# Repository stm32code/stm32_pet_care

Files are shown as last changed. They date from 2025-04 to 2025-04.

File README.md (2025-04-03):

基于STM32单片机物联网智能宠物看护版本1

本文旨在设计一种低成本、低功耗的系统，以STM32为核心芯片，用温湿度、压力、水位、光照等传感器来检测宠物所需的喂食、给水以及所处的环境条件，单片机经过与阈值的比较处理，驱动风扇模块，加湿模块，水泵模块，舵机模块，LED灯，使宠物达到理想生存环境。同时利用Wi-Fi技术将宠物喂养数据上传到OneNET物联网平台，由物联网平台将数据传送到手机APP进行数据监测与反向控制，适用于家庭、宠物店等环境。
绘制原理图和制作PCB板使用Altium Designer软件，相关程序使用Keil软件编程调试，使用OneNET物联网平台作为数据上传中心平台。经过调试最终实现设计目标

可实现如下功能：

1.实时检测宠物环境温度，湿度，光照强度；  																	OK

2.可以通过按键设置温度和湿度阈值，当温度高于（25）阈值时打开风扇降温，当湿度低于阈值60时，打开加湿器加湿；	OK

3.可以根据环境亮度自动调节灯光亮度，如果宠物需要休息也可以手动关闭灯光；									OK

4.可以监测宠物粮食余量，当宠物粮食不足时（<5）发出报警；  OK

5.可以监测宠物饮水机水量情况，当水量不足（<10）时自动加水；

6.可以使用手机APP远程控制系统的各种操作。

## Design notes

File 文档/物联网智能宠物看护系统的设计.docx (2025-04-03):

物联网智能宠物看护系统的设计

学生专业：
学生姓名：
指导教师：

# 摘 要

如今社会随着科学技术的进步和居民生活水平的提高，更多的人开始选择喂养宠物。然而，宠物喂养也存在不少难题。例如，由于工作、旅游和学习等原因，导致主人不能随时看护宠物，因此，为了解决宠物无人照料的问题，研制了一种能够自动给宠物喂食、喂水并为宠物提供合适的生活环境的宠物家庭系统。

本文旨在设计一种低成本、低功耗的系统，以STM32为核心芯片，用温湿度、压力、水位、光照等传感器来检测宠物所需的喂食、给水以及所处的环境条件，单片机经过与阈值的比较处理，驱动风扇模块，加湿模块，水泵模块，舵机模块，LED灯，使宠物达到理想生存环境。同时利用Wi-Fi技术将宠物喂养数据上传到OneNET物联网平台，由物联网平台将数据传送到手机APP进行数据监测与反向控制，适用于家庭、宠物店等环境。

绘制原理图和制作PCB板使用Altium Designer软件，相关程序使用Keil软件编程调试，使用OneNET物联网平台作为数据上传中心平台。经过调试最终实现设计目标

关键词：宠物看护；传感器；物联网平台；Altium Designer；Keil

# ABSTRACT

Nowadays, with the progress of science and technology and the improvement of residents' living standards, more people begin to choose to feed pets. However, there are also many problems with pet feeding. For example, due to work, travel and study, the owner cannot take care of the pet at any time. Therefore, in order to solve the problem of unattended pets, a pet home system that can automatically feed and water the pet and provide a suitable living environment for the pet is developed.

This paper aims to design a low cost, low power consumption system, with STM32 as the core chip, using pressure, water level, temperature and humidity, light and other sensors to detect the feeding and feeding water and environmental conditions required by pets, microcontroller after comparison with the threshold, driving fan module, humidifier module, water pump module, servo module, LED lamp, Make the pet achieve the ideal living environment. At the same time, the Wi-Fi technology is used to upload the pet feeding data to the OneNET Internet of things platform, and the Internet of things platform transmits the data to the mobile APP for data monitoring and reverse control, which is suitable for families, pet stores and other environments.

Altium Designer software was used to draw schematic diagrams and make PCB boards, Keil software was used to program and debug related programs, and OneNET Internet of things platform was used as the data upload center platform. After debugging, the design goal is finally achieved

Key words: Pet care，Sensor，Internet of things platform，Altium Designer，Keil

# 目 录

# CONTENTS

# 第1章 绪论

## 1.1 研究背景和意义

首先，随着人们生活，消费水平的提高，越来越多的家庭选择养宠物，这也为宠物市场的发展提供了机会。其次，由于很多场合，比如外出旅游、学习、工作等都无法将宠物带在身边，那么宠物的喂养在无人的情况下就难以得到满足。此外，随着人们对宠物健康和安全的关注度越来越高，他们也更关注宠物所面临的挑战和风险。因此，智能化的宠物管理监测系统可为消费者提供更加便捷和有效的服务。

其次是智能宠物看护设备的市场自我更新需要，随着物联网技术不断发展，相关产品的更新迭代越来越快，以及生活水平的提高，人们对于宠物的关注度也在不断上升，一般的产品不能满足用户的需求。同时也有越来越多的人开始投入到这一领域中来，越来越多的人开始尝试着去养宠物，从而带动了与宠物相关的市场迅速发展，并且还在以极高的速度快速发展与壮大。这就使得智能宠物看护产品在市场中也占据了一席之地。然而，智能宠物看护产品的快速发展也是一把双刃剑，由于市场中还没有足够多的智能化程度高且经济实惠的智能宠物看护设备，因此用户在使用过程中，所体验到的产品使用体验满意度较低，差强人意。

最后就是智能宠物看护设备便于宠物主人管理，物联网智能宠物看护系统可以为宠物主人提供一个便捷的宠物管理平台，可以让他们随时随地地对自己的宠物进行监测和管理，通过手机上的APP等终端设备，宠物主人可以实时了解到他们的宠物的健康状况、喂食等信息，及时采取措施对其进行照顾，同时也可以方便快捷地对其进行检查和诊断，及时发现问题并进行有效处理。能够有效解决目前因主人外出导致的宠物无人照看的问题

综上所述，物联网智能宠物看护系统的研究意义不仅仅在于可以为宠物提供更好的健康管理和喂养服务，还可以为宠物主人提供更为便捷的管理服务，实现更加智能化、自动化和个性化的管理。此外，随着物联网技术的发展，还可以实现智能家居建设，从而为宠物家庭带来更多便利和安全。

## 1.2 国内外智能宠物看护设备研究现状

### 1.2.1 国内研究现状

2017年，东南大学成贤学院电子与计算机学院的邵彦达、沈睿、眭耀宇发表的基于AT89C51单片机的智能宠物家居一文中，对于智能家居的研究中以AT89C51单片机为核心，利用几个I/O口实现对压力传感器的控制来实现对食物重量和饮用水重量的检测，来实现简单的宠物无人喂养，该设计简约方便，成本低，功耗低，且该设计抗干扰性能好，可靠性高[1]。但存在些许缺点，检测参数少，不能充分实现对宠物的喂养，另外不能实现远程监测和控制功能。2019年，周锦荣、张振宇、袁忠强设计的无线物联网控制的视频监控相结合的宠物喂养系统模型，以拓宽宠物智能喂养和管理方法为目的，使用STM32为主控芯片，驱动控制芯片，将以无线网络传感器为核心的物联网技术（IOT）应用到宠物喂食器的设计中，通过CCD传感器与微处理器控制技术，实现对宠物的智能喂食与监控，使宠物的饲养具有连接与感知的功能，从而提高饲养的精度与管理的效率[2]。但是没有遥控，只有喂食和监控的功能。2021年，由吴明泽，胡立夫，胡家瑞，吴晓宇等人联合研发，研制出了一款具有自主喂食、饮水、远程监控、远程控制等多种功能的智能宠物家庭。由STC89C51单片机作为平台，手机客户端和机器人终端构成，机器人终端使用摄影技术对宠物猫狗进行实时的录像，并通过视频通信技术将录好的视频发送到手机的客户端[3]。无线通信以网络为主要的传输媒体，机器人会按照主人制定的饮食规则，在一定的时间内给宠物们分发食物和饮料，并把宠物们的饮食信息发送到手机客户端。用户还可以通过电脑控制机器人上的摄像头，实时监控宠物的状态，保证宠物的喂食。缺点是成本较高，监测数据不全。

国内市场上有着不少宠物喂养设备，在京东APP上搜索查看后发现总体可分为两大类：单一喂食与喂水喂食两大类。其中单一喂食拿小米旗下的产品作为例子，众所周知如今的小米的智能家居生态链做的如火如荼，在宠物家居方面也是同样有所涉及。在京东上的一款产品可以连接米家APP，可随时随地控制出粮时间与数量，为宠物设置全天候定时定量自动喂食计划，放心出行，使喂养更科学更便捷[4]。但是缺点也显而易见：功能单一，仅有喂食功能，且不能监测宠物的生存环境状况。第二类就是既能喂食又能喂水，以联想旗下的产品为例：饮水、喂食、监控三合一减少多台设备的占地面积，让家里更整洁,宠物拥有更大玩耍空间一体化设计,防止宠物打翻。净水污水分离，可称重食盘，智能APP控制，红外高清摄像头，配备多猫识别功能。可谓是功能强大，一千多的价格也是令人望而却步，而且在用户的使用体验中也存在着不少抱怨，产品质量不合格，个别功能无法实现等。用户花了如此大的价钱却得不到相应的体验。总之如今的市场急需一款经济实用的智能宠物家居设备。

### 1.2.2 国外研究现状

现在，国外也在研究智能宠物家庭系统。2016年Kim Seungcheon在《Smart Pet Care System using Internet of Things》一文介绍了一种在物联网环境下工作的智能宠物护理系统。拟建智能宠物护理系统的基本服务包括:远程喂食、遥控自动排便、闭路电视服务、智能手机APP，可提供上述服务的控制信息[5]。自动给料机的基本功能和市场上能找到的产品大多是一样的。区别在于沟通能力和感知能力。设计了带有重量传感器和定时器的自动给料机。它可以测量食物的量和检查时间间隔。并可定时操作，设有定时装置。用户可以为宠物设定定时喂食时间间隔。此外，用户还可以根据一次性食物量的重量来设定食物量。每一个设置的控制都可以通过用户的智能手机完成。采用Arduino单片机实现了自动给料机。用户可以通过开发的特定智能手机APP查看自动给料机的状态。2020年Nenny Anggraini在研究《Mobile-based monitoring system for an automatic cat feeder using Raspberry Pi》中提出了一种基于树莓派的猫咪自动喂食系统，该项目的目标是利用一台网络摄像机，将一台步进马达与一台树莓派主机相连，用以监视猫咪吃食的情况。你可以用一个摄像头来拍照或者录像。步进马达可转动给料阀，经由GPIO管脚，向树莓派中插入程序。接下来，树莓派将连接到互联网和服务器网络，这样就可以通过移动端的网络浏览器或远程网络视图来完成系统控制。该系统的整体功能包括直接或定时给猫喂食，以及监测喂食周围的照片或视频[6]。

国外的实用设备也有不少公司在做，现列举以下几个公司，Petnet：这是一家位于美国的公司，主要生产智能宠物喂食器。它的智能喂食器可以通过智能手机应用程序进行控制和监测，可以根据宠物的体重、年龄、品种和活动水平等信息，自动计算每顿饭的分量和喂食时间；SureFlap：这是一家英国的公司，生产智能宠物喂食器和智能宠物门。它的智能喂食器可以通过微型芯片识别宠物，并根据宠物的食量和饮食需求，自动分配食物；Feed and Go：这是一家位于英国的公司，生产智能宠物喂食器。它的喂食器可以通过智能手机应用程序进行控制，可以设置多个喂食时间和分量，并监测宠物的食量和饮食情况。

整体上分析来说国外的智能宠物喂食产品存在的情况与国内大同小异，功能不够齐全，成本偏高，用户体验不够好。

## 1.3 设计主要内容

《物联网智能宠物看护系统的设计》以STM32单片机为主控，通过光照，温湿度,压力,水位传感器，来检测宠物需要的投食量供水量和适宜环境数据，单片机经过与阈值的比较处理，使驱动加湿模块，风扇模块，喂食喂水模块使宠物达到理想生存环境。同时利用Wi-Fi技术将宠物喂养数据上传到物联网平台，由物联网平台将数据传送到远端App进行数据监测与反向控制，适用于家庭、宠物店等环境。

主要研究内容分为以下三个部分:

1. 硬件系统部分：各传感器模块采集数据发送给主控芯片，根据主控芯片分析结果，控制水泵、风扇、舵机、加湿器等部分。
2. 物联网平台通信部分：与硬件接口部分、利用Wi-Fi模块与物联网平台通信部份、与软件系统接口部分。
3. 软件系统部分：通信的接口部分和客户端App界面部分。

# 第2章 总体设计方案

物联网智能宠物看护系统是对宠物平时的喂养看护进行的设计，本章会对不同的设计方案进行简单介绍与比较并选取最佳的方案来实现设计目标。

## 2.1 系统总体结构

系统总体结构框图如下图2-1所示

图2-1 系统总体结构框图

如图所示，整个设计以STM32F103C8T6为主控芯片，通过温湿度传感器，压力传感器，水位传感器,光照传感器来检测采集宠物的各种数据，然后传输到STM3单片机，经过处理后显示在OLED上，并且与预先设定好的阈值比较后，驱动加湿模块，风扇模块，投食供水模块，光照模块进行相应的动作。同时通过WiFi模块将采集到的各种数据上传到物联网平台，由物联网平台再将这些数据传送到手机APP终端来进行数据的监测与反向控制，完成整体系统的实现[7]。

## 2.2 设计方案的选择

整个系统设计不仅需要主控芯片完成对多个传感器：压力传感器，温湿度传感器，水位传感器，光照传感器采集的信息进行检测和读取并上传到物联网平台，还需要驱动风扇模块，加湿模块，投食喂水模块，光照模块。通过OLED屏幕和WiFi模块与手机连接后实现人机交互，对宠物生活的各项数据进行监测与管理。结合各方案的可行性研究，总结了以下几种主流的嵌入式智能宠物喂养系统的方案。

方案一：基于STC89C51的设计方案：STC89C51是STC MCU系列中的一种单片机芯片。该系统以FLASH核心为核心，运行速度快，运算能力强，外围设备丰富。下面是关于STC89C51的详情：

1. 内存：STC89C51包含32KB的闪存程式记忆体，可用来储存程式码及资料。另外，其SRAM容量为1KB。
2. 外设资源：STC89C51整合了多种外设资源，其中包含四个16位的计时器/计数器，两个串口（UART)，一个SPI总线接口，一个I2C总线接口，一个PCA计时/计数器，以及一个ADC模拟-数字转换器等[8]。
3. 接口：STC89C51的输入输出接口40个，其中常规接口32个，可编程中断接口8个。
4. 时钟部分：STC89C51以12兆赫兹的晶体振荡为主要频率，经锁相环倍频后，其工作频率最高可达72兆赫兹。
5. 电源部分：STC89C51芯片具有低功耗模式，掉电检测，重置电路等多种功率控制功能。
6. 编程方法：STC89C51支持内部系统编程（ISP）的编程方法，也就是说，可以在该系统中对FLASH程序内存进行直接的编程。

总结来说，STC89C51是一款有着非常优秀性能的单片机芯片，它拥有非常丰富的外部设置资源和强大的计算能力，并且还支持ISP编程，因此它可以被广泛地运用到各种应用中去。尽管STC89C51是一种性能优良的MCU芯片，但是STC89C51也有其不足之处，第一存储容量比较小：STC89C51的 flash程序存储容量仅为32KB，相对于现在的单片机芯片来说，稍显不足。第二缺少DMA功能：由于STC89C51没有直接存储器存储器存储器存储器直接存取（DMA）能力不足，造成了数据传输的效率比较低下。第三没有足够的中断向量：STC89C51仅仅支持5个中断向量，相对来说比其他芯片较少，可能会限制设计应用的需求。综上使用STC89C51作为主控芯片的话虽然在程序编程方面较简单，成本较低，但其处理能力有限，在运行多项功能时可能会发生宕机情况，造成芯片发热，数据异常等现象。

方案二：基于树莓派4B的设计方案：树莓派4B是由Raspberry Pi基金会开发的一款功能强大的单板计算机。首次发布于2019年，是树莓派3B+的升级版，提供了更高的性能和更好的扩展性，是一款功能丰富的单板计算机，可以广泛应用于物联网、机器人、智能家居等领域，以下是树莓派4B的主要特点：

1. 处理器：树莓派4B采用Quad-core Cortex-A72 64位ARMv8处理器，主频高达1.5GHz，比树莓派3B+性能提升三倍以上，可轻松运行各种应用程序和多媒体任务。
2. 内存：树莓派4B最高可搭载8GB LPDDR4-3200 SDRAM，比树莓派3B+提升四倍以上，能更快地处理大量数据，并运行更大规模的程序。
3. 存储空间：树莓派4B提供两个micro HDMI接口，支持4K显示输出，还有两个USB3.0接口，可使用更快的存储设备。
4. GPIO：树莓派4B提供了40个GPIO引脚，可用于连接各种传感器、执行器和其他外设。
5. 操作系统：树莓派4B可运行多种操作系统，包括Raspberry Pi、Ubuntu等，并支持Docker和Kubernetes等主流容器服务。

树莓派4B拥有着丰富的功能，但与此同时也存在一些缺点。首先，树莓派4B价格比之前的版本略高，这使得它在同类产品中并不是最为经济实惠的选择。其次，随着处理器性能的提升，整体功耗也有所增加，容易引起散热问题。使用时需要特别注意散热，否则会影响系统的稳定性和寿命。最后，由于硬件配置的变化，一些老的软件和扩展板可能不再兼容，需要重新编译或更新。

方案三：基于MSP430的设计方案：MSP430是由德州仪器（Texas Instruments）公司开发的具有极低功耗，高性能，操作简单的MSP430芯片。MSP430芯片因其独特的结构和优异的计算性能，在嵌入式、物联网等领域得到了广泛的应用。其主要特征如下：

1. 低功耗：MSP430的功耗非常低，它具有多种进入睡眠状态的方式，在低功耗模式下，耗电量可以降低到微安级别，非常适合于需要长时间待机的嵌入式应用。
2. 高性能：MSP430采用16位RISC架构，能够在相对较短的时间内完成复杂的运算，并支持DSP指令集和提供硬件加速器的FRAM存储器。
3. 易于编程：MSP430支持多种编程工具和编程语言，如MSP430-GCC、Code Composer Studio（CCS）和IAR Embedded Workbench等，还可通过USB接口进行在线编程和调试。
4. 强大的外设：MSP430内置了丰富的外设，包括多个定时器、比较器、ADC和DAC等，同时还支持多种通信接口和协议，如SPI、I2C、UART、USB等。

总之，MSP430芯片具有低功耗、高性能、易用等特点，在嵌入式、物联网等领域有着广阔的应用前景。但是也有其缺陷。首先，其处理器运行速度缓慢，仅为25MHz，不能满足高性能计算的需要。其次，一般情况下，MSP430的闪存空间仅为几KB至几十KB，不能满足较大规模的应用。此外，MSP430的外设资源相对较少，例如只有一个UART、一个SPI和一个I2C接口，无法满足复杂应用的需求。

方案四：基于STM32的设计方案：STM32单片机系列是一种以ARMCortex-M核为核心的嵌入式微处理器，这是一个面向高性能，低成本，低功耗，低功耗的嵌入式系统，其特征如下：

1. 较为丰富的外围接口：多个通用的输入输出口（GPIO）、模数转换器（ADC）、数字模拟转换器（DAC）、通用同步/异步收发器（USART）、串行外设接口（SPI）等等，可以满足用户的各种需求[9]。
2. 处理性能强：采用了ARM Cortex-M系列架构，处理性能高，适用于高速数据处理和复杂的算法。
3. 低功耗设计：STM32单片机具有较强的低功率特性，可根据需要自动切换到休眠状态和备份状态，从而达到最小化功耗的目的。
4. 灵活的开发工具和环境：STM32单片机可以使用多种开发工具如Keil、IAR等进行开发，同时也支持多种编程语言，如Assembly、C++等等。
5. 安全性高：STM32单片机具有硬件加密，防篡改，以及内部不掉电操作的保护等先进安全设计。

综上所述，STM32 MCU有较强的处理能力，较低的功耗，丰富的外部接口，灵活的开发方式，以及较高的安全性，可用于多种应用场合。虽然略微存在一些不足，比如需要更多的专业知识，对编程语言能力要求高等，但经过学习都可以克服。

通过以上四种方案的分析与对比，由于设计需要检测宠物各项生活数据，驱动各模块准确运行，与手机APP相接并反向控制等要求，且应具备低成本、可以量产商用的特性，并可以根据方案其他需求扩展相关外设，故选用方案四的基于STM32单片机的设计方案。

# 第3章 硬件设计

本章主要是对硬件部分进行设计，其中包括充最小系统电路，电源电路，WiFi电路，传感器部分，显示部分，按键部分，驱动部分，报警电路的介绍；

## 3.1 STM32F103C8T6最小系统

STM32F103C8T6是一款由意法半导体公司推出的基于Cortex-M3内核的32位微控制器，硬件采用LQFP48封装，属于ST公司微控制器中的STM32系列，它的GPIO有8种模式，包括上拉、下拉输入模式，所以在连接按钮时可以不设计上下拉电阻[10]。

STM32F103C8T6单片机具体参数如下：

1. GPIO：总共有37个GPIO，分别为PA0-PA15、PB0-PB15、PC13-PC15、PD0-PD1。
2. ADC：有2个12bit ADC合计12路通道，外部通道：PA0到PA7+PB0到PB1，内部通道：温度传感器通道ADC_Channel_16和内部参考电压通道ADC_Channel_17[11]。
3. Timers：4个16bit定时器/计数器，分别为TIM1、TIM2、TIM3、TIM、TM1带死区插入，常用于产生PWM控制电机；2个看门狗定时器（独立看门狗IWDG、窗口看门狗WWDG）；1个24bit向下计数的滴答定时器[12]。
4. 通信串口：2*IIC，2*SPI，3*USART，1*CAN。
5. 系统时钟：可以使用内部8MHz时钟HSI，最高倍频达到64MHz；也可以使用外部8MHz时钟HSE，最高可倍频可达到72MHz[13]。

STM32F103C8T6的最小系统主要由时钟电路，复位电路两部分组成，如下图3-1所示。其时钟电路包含两个主要部分：外部振荡器和内部时钟源。外部振荡器是用来提供芯片整体的系统时钟，通常使用一个陶瓷振荡器或者晶体振荡器作为外部振荡器，其频率通常为8MHz。此外，还可以连接一个30pF的并联电容以稳定振荡器的工作。

复位电路是一项非常重要的设计，它用于确保芯片在开机或者其他异常情况下能够正确地启动并进入预设状态。包括一个复位电平检测电路和一个RC电路，用于检测系统电源是否正常以及芯片是否工作不正常。当系统电源异常或者芯片出现故障时，复位电路会强制将芯片复位，进入复位状态，执行复位向量指向的地址，重新启动系统。

图3-1 STM32F103C8T6最小系统

## 3.2 电源部分设计

### 3.2.1 电源输入电路设计

电源输入部分考虑使用5V电源输入，一方面满足低功耗安全节能的目的，另一方面满足一些模块需要5V电压供电的需求，而对于STM32单片机和其他后续需要3.3V电压供电的模块，再进行电压转换。这里电源接入使用的是DC-005插座，材料耐高温，价格低廉，性价比高。电源输入电路原理图如下图3-2所示。

图3-2 电源输入电路原理图

### 3.2.2 WiFi电源转换电路设计

由于使用的WiFi模块ESP8266-01S的输入电压要求是3V-3.6V与STM32F103C8T6要求的电压相同，不可以使用电源直接输入的电压，所以这里需要设计一个WiFi电源转换电路将5V电压转为3.3V。

电源转换电路使用稳压器AMS117-3.3，它的稳压调整管是由一个PNP驱动的NPN管组成的，漏失电压定义为：

(3-1)

Vdrop————芯片内部导通时产生的压降;

VBE————三极管的基极和发射极之间的电压;

VSAT————三极管饱和电压

其基本电压转换公式为：

(3-2)

Vin————输入电压；

Vout————输出电压；

Vadj————外部校准电压。

其中Vdrop和Vadj在AMS1117的数据手册中提供了标准值[14]。需要注意的是，这里的输入电压和输出电压都是直流电压。如果需要将交流电压转换为直流电压，则需要使用整流和滤波等电路进行预处理。

在电源输入电路中，电容并联可以起到减少电源噪声、过滤掉高频噪声等作用，从而提供更稳定、更纯净的电源给负载电路。当电源由于传输线路、开关电源等因素导致的干扰噪声时，加入电容可以削弱这些噪声，起到去除干扰的作用。另外，电容并联还可以对电源电流进行平滑，防止瞬间电流过大造成电源电压下降，从而保证负载电路的正常工作。

具体来说，电容的充放电过程是一个相位相反的过程。当电源电压下降时，电容器可以通过释放其储存的电能，为负载电路提供额外的电流，从而稳定输出电压；当电源电压上升时，电容会吸收过剩的电流，防止过压，保护负载电路。转换电路的原理图如下图3-3所示。

图3-3 WiFi电源转换电路

为了保证AMS1117工作的稳定性，使用可调电压版本时，需连接至少一个22μF的钽电容至输出端，而固定电压版本则可使用较小的电容，具体容量还需据实际应用而定[15]。一般而言，随着输出电流增加，线性调节器的稳定性会降低。

## 3.3 WiFi模块部分设计

WiFi模块部分计划采用ESP8266-01S作为首选，可以用于快速连接互联网的物联网设备和小型嵌入式系统。ESP8266由中国乐鑫公司推出，是一种低功耗、低成本、高性能的系统级芯片，可在-40℃~125℃工作。选择使用ESP-01S型模块，它可以采用串口的无线AP（COM_AP）模式、串口的无线STATION（COM_STA）模式、串口的无线AP+STA（COM_AP&STA）模式，并且还具有一键配网（smartConfig）功能[16]。

ESP8266-01S这是一个类似于ESP-01的无线网络模块，但是在原来的基础上得到了更新和改善。本模组自带Wi-Fi功能，可与Wi-Fi直接联接，是一款性价比很高的物联网装置。ESP-01S具有八个插脚，其中两个插脚（VCC,GND)，两个TX/RX通讯插脚，四个GPIO插脚。电路原理图如下图3-4所示。各引脚功能介绍如下：

1. VCC：支持3.0V至3.6V电压输入的电源供电引脚。
2. GND：接地引脚。
3. CH_PD：芯片使能脚，用于将模块从低功耗模式的状态唤醒。
4. RST：重置引脚，将引脚电平拉低即可重置该模块。
5. TXD：串行通信发送数据，可以通过AT指令或固件程序来进行控制。
6. RXD：串行通信接收数据，可以通过AT指令或固件程序来进行控制。
7. GPIO0：通用的输入/出引脚，可控制LED和其他外部设备。
8. GPIO2：通用的输入/出引脚，可控制LED和其他外部设备。

图3-4 ESP8266-01S电路原理图

需要注意的是，在ESP8266ESP-01S通电后，系统将自动切换到串行烧录模式。如果要使固件程序正常运行，则必须同时拉高GPIO0和RST管脚（也就是与VCC连接）。

ESP8266-01S具有COM-AP模式，COM-STATIOM模式，以及COM-STA+AP模式，每一种模式都有其独特的作用和适用场合。其中，串口型的Wireless AP（COM_AP）模式，以该模块为热区，利用其它设备对ESP8266-01S模块进行访问，并利用串口进行信息交换。串口无线STA（COM_STA）模式则是将模块作为客户端，用于将模块接入其他热点来构建WiFi网络。而串口无线AP+STA（COM_AP&STA）模式则是既可以将模块作为热点，供其他设备访问，又可以接入到其他WiFi网络，它是前两种模式的综合[17]。

在开始初始化的时候，单片机通过串口通信的方式，模块的最初配置和发送命令的操作是利用AT指令来完成的，其中的一些AT指令见表3-1。

表3-1 AT指令

AT指令 | 描述
AT | 测试AT启动
AT+RST | 重新启用模块
AT+GMR | 查看版本信息
AT+GSLP | 开启深度睡眠功能
ATE | 开启和关闭回显功能
AT+RESTORE | 恢复原出厂设置
AT+UART | 设置串口的配置
AT+CWMODE=1/2/3 | 选择不同的工作模式

## 3.4 传感器部分设计

### 3.4.1 温湿度检测部分

温湿度检测部分利用DHT11温湿度传感器对宠物生活环境进行温度和湿度的监测。常见的DHT11有以下4个引脚，电气原理图如下图3-5所示。

1. VCC：传感器的正极供电引脚，工作电压的范围是3V到5V。
2. GND：传感器的负极供电引脚，需要进行接地。
3. OUT：传感器输出的数据信号引脚，可以通过单片机进行采集并处理。
4. RES：传感器的复位引脚，将引脚电平拉低一段时间即可对进行复位。

图3-5 DHT11电气原理图

应当指出，DHT11的数据信号管脚仅能进行数字输出，而不能进行模拟输出。当读取传感器的数据时，特殊的通信协议是必需的。DHT11在单片机能够读取一个确认信号时，就发出一个80微秒的高电平信号，并以50微秒的时间间隔将数据上传至MCU。湿度计算公式为：

(3-3)

RH——湿度值；

rh高——湿度数据高8位；

rh低——湿度数据低8位；

温度计算的方法同湿度的计算方式相同。基于此，可以读取此时的温湿度信息。在此状态下，传感器开启一次温湿度采集，然后通过ESP8266上传到物联网云平台。当采集完后，DHT11自动切换到低功耗模式[18]。

### 3.4.2 压力检测部分

HX711是一款24位模数转换芯片，用于高精密载荷传感器，它的特点是高集成度，高响应速度，高抗干扰能力。HX711在读出感测器数据时，使用差分输入方式，能有效地排除外界的干扰，使感测器的工作更稳定、更准确。支持两种工作模式：编程模式和工作模式。编程模式是用于初始化和校准HX711的内部参数，工作模式是用于读取外部传感器的数据。在使用HX711时，首先需要与外部传感器相连接。通常情况下，HX711需从外界传感器接受正、反两种输入讯号，才能对输出讯号进行差分读取。之后，经由PD_SCK (引脚选择位）、DOUT(数据输出管脚）与单片机进行SPI通讯，以实现数据的读出。

计算传感器供电电压：HX711可以在产生VAVDD和AGND电压，即HX711模块上的E+和E-电压[19]。通过下式（3-2）计算：

(3-4)

VAVDD——内部稳压电路的输出电压；

VBG——芯片的输出参考电压

例如：VBG为2.5V，R1=10K，R2=5.2K，因此得出VAVDD=7.31V。

测重原理：满量程输出电压=激励电压*灵敏度 (https://so.csdn.net/so/search?q=%E7%81%B5%E6%95%8F%E5%BA%A6&spm=1001.2101.3001.7020)1.0mV/V。例如：供电电压3.3V乘以灵敏度1.0mV/V=满量程3.3mV，相当于有3.3Kg重力产生时候产生3.3mV的电压[20]。

HX711该芯片需经四根管脚与单片机相连。其中，两个引脚为通讯用，另两个引脚为接收换能器的模拟电信号。原理图如下图3-6所示。

1. VCC：为芯片提供3.3V或5VDC供电的数字电源管脚。
2. GND：地线管脚，要求与该系统的地线相连。
3. SCK：MCU用于控制晶片内变换时序的时钟线路。
4. DOUT：在操作方式中，从其输出芯片测得的ADC值（24位）的数据输出管脚。

图3-6 HX711原理图

### 3.4.3 水位检测部分

液位传感器可采用物理接触法、压力传感法、声纳法等多种方法对液位进行检测。在此设计中，使用了Water Sensor作为水位感应器，该感应器是一种用于探测水位或水滴的辨识感应器，使用方便，性能价格比高。

Water Sensor有两个电源引脚VCC和GND，以及一个输出引脚：将检测到的水分信号转化为数字或模拟电信号输出，可以通过该引脚读取传感器检测到的水分含量数据。计算公式如下：

(3-5)

h——表示液位高度；

C——表示传感器测得的电容值；

C0——表示传感器在空气中的电容值；

k——表示传感器的灵敏度常数。

Water Sensor的检测原理是通过一系列的暴漏的平行导线线迹对水滴或者水量的大小进行测量进而判断水位[21]。在水与传感器的电极相接触时，将产生一个回路，使电流通过该回路，再回到控制系统中。该模块主要利用的是三极管的电流放大原理，当液位高度使三极管的基极与电源正极导通时，在三极管的基极和发射极之间就会产生一定的电流，这时在三极管的集电极和发射极之间就会产生一个一定放大倍数的电流，通过发射极的电阻产生特征电压，被AD转换器采集[22]。完成水位到模拟信号的转换之后，可以直接将输出的模拟信号连接至单片机，实现对水位进行测量。该传感器模块的电气原理图如下图3-7所示。

图3-7 水位检测原理图

### 3.4.4 光照检测部分

光照传感器（Light Sensor）是一种对外界光线进行检测的光电传感器。他们能侦测到光的出现以及光的明度，然后把这些量度转换成电信号，以便电脑或其它装置来读取。此部分采用光敏电阻5528，这是是一种根据内光电效应，把光照射到敏感表面上，使电阻值变化的半导体元件。光照越强，阻值就越低，随着光照强度的提高，电阻值急剧下降，甚至可小到1Ω以下[23]。因此，这种光敏电阻应用于光电传感器时，可根据光亮的强弱来进行控制。

单片机的PA5引脚用于AD采集，又因为STM32单片机的电压限制不能高于3.6V，而5528的电压为5V，所以为了使用两个电阻起分压作用来保证电压不超过单片机的正常工作电压。电气原理图如下图3-8所示。

图3-8 光照检测部分原理图

光敏电阻的阻值用R5528表示，PA5的电压用VAD表示，R11阻值为1000Ω，R12阻值为1500Ω，则可得下式：

(3-6)

单片机的正常工作电压为3.3V，ADC最大值为4096，将光敏电阻实时对应的AD值用X表示则可得下式：

(3-7)

然后将式（3-4）与式（3-5）联立可得：

(3-8)

通过ADC可以计算出X，也就可以根据上式求出光敏电阻的值，根据不同的电阻便可得到不同的光照强度大小。

## 3.5 显示部分设计

OLED屏幕具有高对比度、自发光、薄厚度、无需背景光源、宽视角、快速响应的优点。分为七针的SPI/IIC兼容模块，以及四针的IIC模块，设计中使用的是的四针的IIC模块。以现在的科技水平，OLED的体积还无法扩大，但分辨率却是可以达到的，这种屏幕的特点如下：

1. 0.96寸的发光二极管，有黄色、蓝色、白色三种色彩。
2. 分辨率为128x64。
3. 多种接口方式；OLED裸屏一共有以下种接口，分别是：6800,8080两种并行接口方式，3线或4线串行SPI接口模式，IIC接口模式（只要两条线路就能对OLED进行控制)，这五种接口是通过屏上的BS0-BS2来配置的[24]。

原理图如下图3-9所示。0.96英寸4针OLED有四根管脚，分别是正极（VCC）、负极（GND）、时钟线（SCL）、数据线（SDA)，其中VCC和 GND管脚是用来连接电源的，通常是3.3伏或者5伏。其中，SCL、SDA管脚分别为两条IIC接口的信号线路，用以与单片机进行通讯，完成对OLED器件的控制及数据传送。

图3-9 OLED原理图

## 3.6 按键部分设计

按键部分采用独立按键，是一种常用的电子器件，在电子器件中用来进行输入控制。它一般由一个按钮和连接到该按钮的两个引脚组成，当使用者按下按钮时，电路会接通，执行相应的动作。

独立按键个数很少，可以按照要求灵活地编写代码。而在矩阵式键盘中，键的位置则由行、列编号来决定。独立按键的工作原理比较简单，当按键被按下时，会断开引脚间的电路连接，并让单片机探测到电路中的变化，进而在程序中进行相关的控制与操作。

在利用STM32单片机进行按键转态读取时，将与按键相连的STM32单片机接口分配为1，若按下按键，因为按键的另一端接地，则该管脚被拉低。下图3-10为其原理图。

图3-10 独立按键部分原理图

共使用4个独立按键，这里命名为SW2、SW3、SW4、SW5。设计的功能分别为：用SW2控制模式的切换，即对温度，湿度的阈值进行设置；SW3按下为加；SW4按下为减；SW5为手动控制灯光的开关。

## 3.7 驱动部分设计

### 3.7.1 光照模块设计

光照部分计划使用LED灯来模拟宠物的灯光照射，有两种模式，第一种是自动模式灯光常亮，但是会根据光照传感器检测到的光照强度变换灯光的亮度，光照强度大即环境比较亮的时候，LED灯亮度较弱，当光照强度小即环境比较暗的时候，LED灯会随之变亮；第二种是手动模式，可以通过开关SW5来控制LED灯的亮灭，比如宠物需要休息时，可手动关闭灯光。

使用一个NPN型三极管（FHT9014Y-ME），为使NPN型三极管工作，需在其发射结加正向电压，集电结加反向电压的条件下才能达到导通电压[25]。发射结正偏表现为P端电压高于N端电压（需有适当的电压差），而集电结反偏表现为集电结电压高于基极电压。

图3-11 光照电路原理图

上图3-11为光照电路的原理图。当外部光线强度较弱时，光敏电阻的阻值较大，其两端电压升高，导致三极管基极电压上升，未能达到发射结正偏的条件，此时三极管集电极无电流通过，因此二极管不会发光；相反，在较强的光照下，光敏电阻阻值较小，其两端电压降低，基极电压随之降低并满足发射结正偏条件，此时集电极电压基本等于电源电压，高于基极电压，同时满足了集电结反偏条件，因此形成放大电路，有电流通过，二极管发光。并且光敏电阻阻值的变化，引起电压的变化，即LED灯光的亮度也会随之改变。

### 3.7.2 风扇及加水加湿模块设计

对于此部分计划使用三个继电器，来对风扇模块、加湿模块、加水模块进行模拟，并且可以直接在继电器的另一端接上相应的设备如：风扇，加湿器，水泵，继电器相当于开关使另一端对应的风扇、加湿器，水泵开始工作。

通过单片机接继电器电路，可以实现弱电对强电的控制。这种控制方式常见于工业自动化领域，如机器人、汽车生产线等的控制。通过单片机管脚的高低电平输入，可以实现对大电流负载的控制。

原理图如下图3-12所示。具体来说，MCU的一个输出端口连接到继电器控制电路中的控制端口，当该端口输出高电平时，继电器线圈不被激活，继电器处于关闭状态；当该端口输出低电平时，继电器线圈被激活，继电器吸合，处于闭合状态。这种电路可用于控制灯光、电机、风扇等大电流负载的开关。同时，接入LED灯能够非常直观地展示继电器的闭合情况，方便用户观察判断。

图3-12 继电器电路原理图

继电器驱动有两个主要含义：首先是对继电器本身进行驱动，因为继电器是一个功率器件，需要使用单片机来控制它的开/关状态；其次是利用其去驱动其他大功率负载，比如直接驱动接触器或者中间继电器。因此，继电器驱动不仅是单片机与外部大功率负载的接口，也是实现弱电信号控制强电负载的重要途径[26]。

### 3.7.3 投食模块设计

投食模块的设计采用一个舵机模拟宠物粮仓的开启和关闭，即当称重模块采集到食物重量不足时，经过单片机处理后发出信号，控制舵机旋转一个角度，表示进行投食。经常使用的标准SG90舵机共有三根接线：电源导线 VCC，接地导线GND，控制信号导线。其原理图如下图3-13所示。

图3-13 舵机原理图

舵机使用PWM信号进行驱动，其周期一般为20毫秒（50Hz），脉宽的范围为0.5毫秒到2.5毫秒。在每个周期内，舵机接收到一段PWM信号，通过信号的脉宽来确定需要转动的角度。理论上，脉宽为0.5毫秒对应着0度角，脉宽为2.5毫秒对应着180度角，中间的脉宽则会对应着这两个极端之间的角度值。不同脉冲舵机对应旋转角度如下图3-14所示。

图3-14 不同脉冲舵机对应旋转角度

单片机可以接收来自信号线的PWM控制信号，接着通过内部逻辑电路处理并输出控制信号，来控制舵机电机的转动。同时，电机驱动着齿轮组，经过减速后传动至输出的舵盘。此外，舵盘的输出轴与位置反馈电位计相连。在舵盘进行旋转时，位置反馈电位计也随之旋转，并输出电压信号给控制电路板进行反馈。控制电路板根据位置反馈信号来确定电机的转动方向和速度，从而使目标停止[27]。

## 3.8 报警电路设计

报警电路的设计目的是当宠物余量不足时发声警示。其电路主要由一个蜂鸣器，一个NPN三极管，一个隔离二极管以及一个偏置电阻组成。首先选择一个合适的蜂鸣器，它应该能够产生足够大的音量和频率来引起人们的注意。然后将蜂鸣器的正极连接到一个隔离二极管，以防止反向电流损坏电路。连接一个NPN三极管，将其基极与信号源即单片机的PA8引脚连接，中间接入偏置电阻R16进行保护，收集极与地线连接，发射极与蜂鸣器的负极相连，用来作为开关元件，将输入信号转换为输出信号。在报警电路中，三极管开关可以控制输出负载的通断，从而实现报警功能。报警电路如下图3-15所示：

图3-15 报警电路原理图

三极管的基极保持一个稳定的高电平，当PA8处于高电平状态时三极管反向截止，蜂鸣器无电流通过，不工作。当PA8处于低电平时，三极管导通，蜂鸣器通过电流形成回路发出声响开始工作，直到PA8再次拉高时停止报警。

# 第4章 系统软件设计

本章是对软件部分进行设计，主要是主程序流程设计，以及WiFi，传感器，OLED显示，驱动，物联网平台子程序的设计。

## 4.1 主程序流程图

本程序的主程序流程图如下图4-1所示。

图4-1 主程序流程图

软件主要实现如下功能：

1. 实时检测宠物环境温度，湿度，光照强度。
2. 通过独立按键设置适宜的温度和湿度阈值，当温度高于阈值时打开风扇降温，当湿度低于阈值时，打开加湿器加湿。
3. 根据环境亮度自动调节灯光亮度，也可以手动关闭灯光。
4. 监测宠物粮食余量，当宠物粮食不足时发出报警。
5. 监测宠物饮水机水量情况，当水量不足时自动加水。
6. 使用手机APP查看数据。网页下发指令控制。

程序开始后主控以及OLED屏幕初始化，LED初始化，按键初始化，水位初始化，舵机初始化，DHT11初始化，BEEP初始化，WiFi初始化最后进行称重模块初始化，并且对涉及的变量进行定义。然后判断WiFi模块的工作模式，默认为自动模式即ESP8266接受信号“I”时，当接受到信号“J”时开启手动模式；在自动模式下，各传感器将开始工作，采集信息数据并显示在OLED屏幕上。同时，数据也会被上传到物联网云平台。接着再次判断工作模式，为手动模式时则根据接受到的信号进行相应的动作；，否则直接将数据与所设阈值进行比较，然后判断是否通过按键改变阈值，没有则单片机发出信号使驱动模块进行相应的动作有则再次比较。当工作模式为手动时，各驱动模块根据下发的信号进行相应的动作，信号指令如表4-1所示。然后各传感器工作，采集的数据显示在OLED屏幕上，接着判断工作模式以此循环。

表4-1 信号指令表

信号指令 | 相应动作
A | 风扇开启
B | 风扇关闭
C | 加湿器开启
D | 加湿器关闭
E | 水泵开启
F | 水泵关闭
H | 舵机右转动90°
G | 舵机左转动90°
I | 自动模式
J | 手动模式

## 4.2 WiFi模块子程序流程图

如图4-2所示，首先，进行WIFI模块初始化并设置为STA模式工作，在该模式下ESP8266通过接收路由器的信号而能够连接互联网，如果把它安装在硬件设备上，就可以实现硬件设备的远程控制，可以理解为此时ESP8266是主动去连接其他设备[28]。判断是否连接成功，成功则进入下一步；若未连接则循环执行此步骤。直到连接成功，云平台的连接流程同上，云平台连接成功后，检查是否有数据收发任务。如果有，则执行收发任务；如果没有，则进行热点与云平台连接状态检查的循环。

图4-2 WiFi子程序流程图

## 4.3 传感器部分子程序流程图

按照总体方案设计，传感器信息采集与传输分为多个步骤。如图4-3所示，首先进行温湿度传感器数据采集，然后进行液位传感器信息采集，接着是光照传感器信息采集，最后进行压力传感器数据采集。采集到的数据由信息采集芯片对其进行处理，再由串行接口传送给通信芯片。然后，ESP8266模块会把资料传给OneNET的物联网云端，也会传给移动端的应用程序，实现数据的远程监测与管理。

图4-3传感器子程序流程图

## 4.4 显示子程序流程图

显示部分采用了0.96英寸的OLED显示屏来显示本地数据，并使用IIC控制方法进行数据通讯。当系统通电后，STM32单片机首先需要将与OLED相连接的引脚设置为IIC功能。然后，STM32单片机需要初始化OLED的寄存器，包括地址、片选等寄存器的配置。在初始化完成后，单片机会清空屏幕并开始展示所需的字符，这些字符包括温度湿度名称、亮度、水位、余量，在展示所有固定信息后，STM32单片机会显示每个器件的状态信息，对应于相应的字符。此时，STM32单片机已经成功接收到了每个器件的状态信息。详细的控制流程可参考图4-4。

图4-4 OLED显示子程序流程图

## 4.5 驱动部分子程序流程图

驱动部分程序流程图如下图4-5所示，程序首先进行初始化，如果WiFi模块连接失败则继续初始化，反之连接成功则将各传感器采集到的数据打包发送在OLED屏幕上显示。接着判断工作模式若为手动则根据下发信号控制各驱动模块工作；自动模式下则与阈值进行比较进而通过单片机控制各驱动执行相应命令。

图4-5 驱动部分子程序流程图

## 4.6 物联网云平台设计

### 4.6.1 MQQT传输协议

MQTT是一种以TCP/IP为基础，由IBM于1999年推出的一种基于发布/订阅的轻量级通信协议，现已更新到v3.1.1版本。在MQTT协议的通讯过程中，主要有三个角色参与：发布者（Publish）、代理/服务器（Broker）以及订阅者（Subscribe）[29]。

信息的发布方和订阅方均为客户端，而信息代理则由服务器来提供。同时，信息的发布方也可能是用户本身。通过MQTT协议实现，消息发布者将消息发送到服务器，服务器将消息传给订阅者，从而实现了消息的传输[30]。如下图4-6所示

图4-6 MQQT协议示意图

使用MQTT方式进行数据传输时，当使用的设备接入WiFi网络后，STM32单片机作为客户端会主动连接MQTT服务器。下表4-2为MQQT控制报文类型。

客户端在向服务器发送“CONNECT”报文之前，客户端需要完成一个关键步骤即连接入口的验证过程。一旦服务器确认连接有效，则会返回一个“CONNACK”报文。客户端可以是发布者也可以是订阅者，在实现数据通信前都需要连接到服务器，并完成“CONNECT”和“CONNACK”两个报文的交换。当客户端与服务器成功建立连接后，客户端的联机状态仍然会被客户端与服务器用来确认。

客户端必须周期性地将“PINGREQ”心跳数据包发送到服务器，以指示客户端的联机状态。一旦接收到一个“PINGREQ”的心跳数据包，服务器就会回复一个“PINGRESP”。如果一个客户端没有按时发送一个“PINGREQ”心跳数据包，那么这个客户端就会被服务器所切断[31]。

表4-2 MQQT报文控制类型

名字 | 值 | 报文流动方向 | 描述
Reserved | 0 | 禁止 | 保留
CONNECT | 1 | 客户端到服务端 | 客户端请求连接服务端
CONNACK | 2 | 服务端到客户端 | 连接报文确认
PUBLISH | 3 | 两个方向都允许 | 发布消息
PUBACK | 4 | 两个方向都允许 | QoS1消息发布收到确认
PUBREC | 5 | 两个方向都允许 | 发布收到
PUBREL | 6 | 两个方向都允许 | 发布释放
PUBCOMP | 7 | 两个方向都允许 | QoS2消息发布完成
SUBSCRIBE | 8 | 客户端到服务端 | 客户端订阅请求
SBBACK | 9 | 服务端到客户端 | 订阅请求报文确认
UNSUBSCRIBE | 10 | 客户端到服务端 | 客户端取消订阅请求
UNSUBACK | 11 | 服务端到客户端 | 取消订阅报文确认
PINGEEQ | 12 | 客户端到服务端 | 心跳请求
PINGRESP | 13 | 服务端到客户端 | 心跳响应
DISCONNECT | 14 | 客户端到服务端 | 客户端断开连接
Reserved | 15 | 禁止 | 保留

### 4.6.2 物联网控制台应用程序创建

登录OneNET官网注册自己的账号，然后进入到平台的开发者中心选项。点击控制台的多协议接入即可[32]。具体的添加产品如下图4-7所示。在完成创建产品后，还需要在该产品下创建设备，以对接硬件数据消息。

每个设备都有一个唯一的标识符（ID），可以使用鉴权码来确保它们之间的相互独立性。在创建一个产品时，需要填写名称、鉴权信息等信息，其中鉴权信息是用于验证设备或应用程序访问物联网平台的凭证。通过鉴权信息，可以对设备或应用程序进行身份验证，从而能够一定程度上保证数据的安全性和可靠性。

在本次设计中，设备名称为petcare，鉴权信息为dht11。设备详情信息如下图4-8所示。

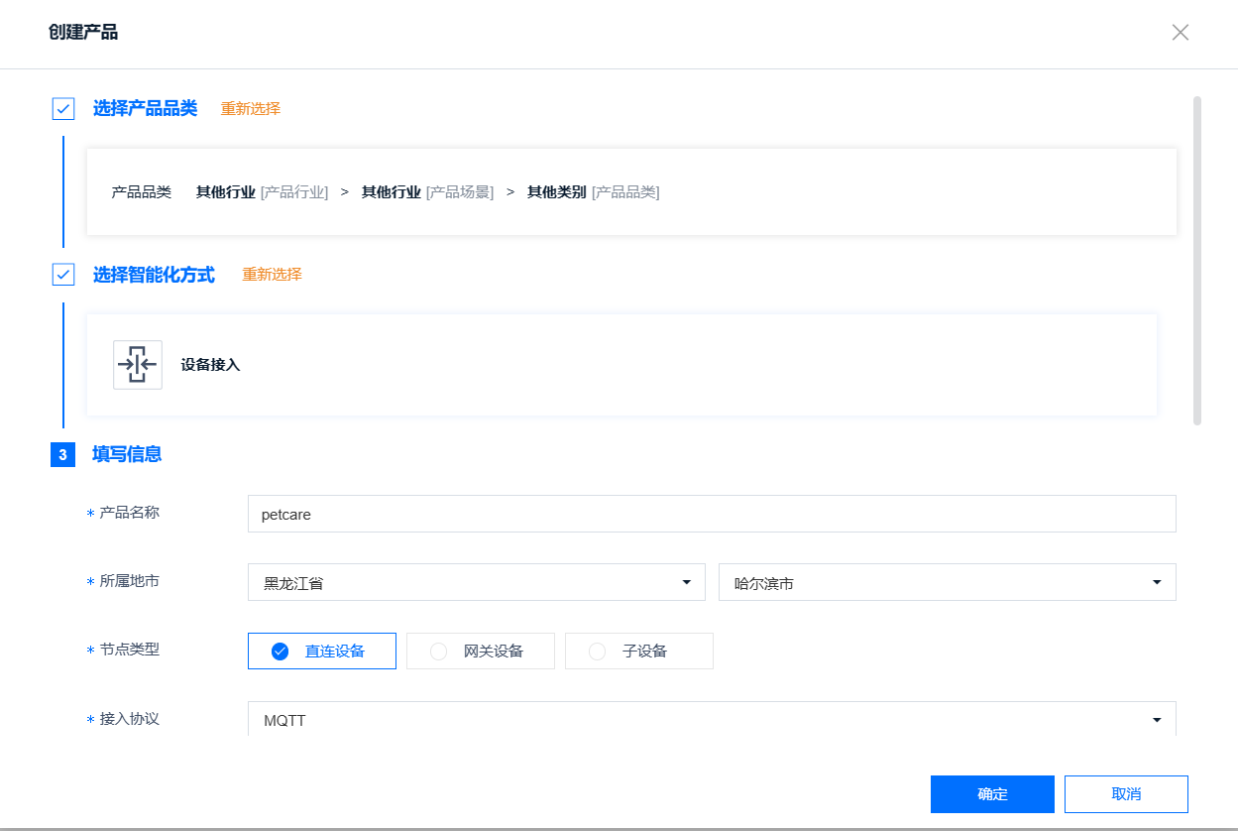
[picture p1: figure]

图4-7 创建的产品信息

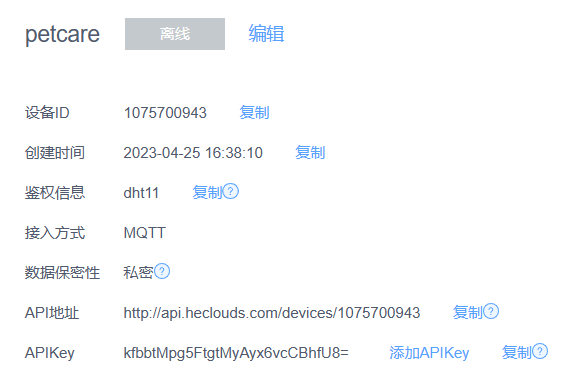
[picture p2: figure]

图4-8 加入设备信息

### 4.6.3 物联网平台通讯程序设计

如图4-9所示，物联网平台的通信流程如下：首先，任务初始化，然后检查ESP8266是否成功连接到OneNET物联网云平台；若连接成功，则执行下一步，否则循环检查直到成功为止。接着判断是否已登录云平台，如果失败则执行登录操作，并再次检查是否已登录。若成功登录，则检查是否收到了来自平台的数据。如果有数据，则解析并执行指令；如果没有数据，则检查是否需要将数据发送到云平台。如果需要，则执行“发送数据到云平台”指令；如果不需要，则返回到WiFi检查，并重复上述流程。

图4-9 物联网平台通讯子程序流程图

# 第5章 系统的调试与实验

本章为系统的实物制作与调试，主要是对PCB板的焊接与调试，以及软件部分的调试，硬件软件相互验证，以达到预期目标。

## 5.1 电路板的焊接与测试

电路板是控制器顺利运行的基础，也是所有元器件的支撑平台。电路板上的器件焊接质量是确保系统正常运行的前提。如果电路板上的器件焊接出现错误，那么下一步电源电路的测试就可能会对控制器造成不可逆转的损伤。因此，将电路板测试放置在整个测试流程的第一步非常重要[33]。

首先将制作好的PCB板与绘制好的原理图进行对比，使用万用表的测电阻功能对各个模块的引脚进行测试，确保连接无误。同时使用万用表仔细检查各焊点避免焊接过程中出现虚焊，缺焊的失误。另外还可以使用万用表在不供电的前提下检查各元件的正负极是否焊接正确。

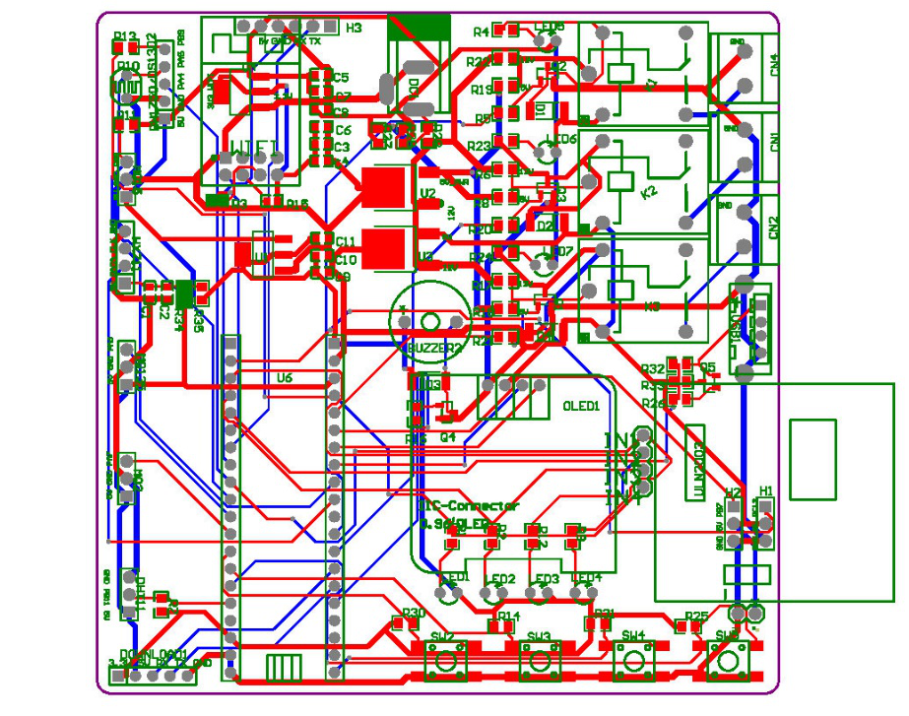
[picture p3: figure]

图5-1 PCB设计图

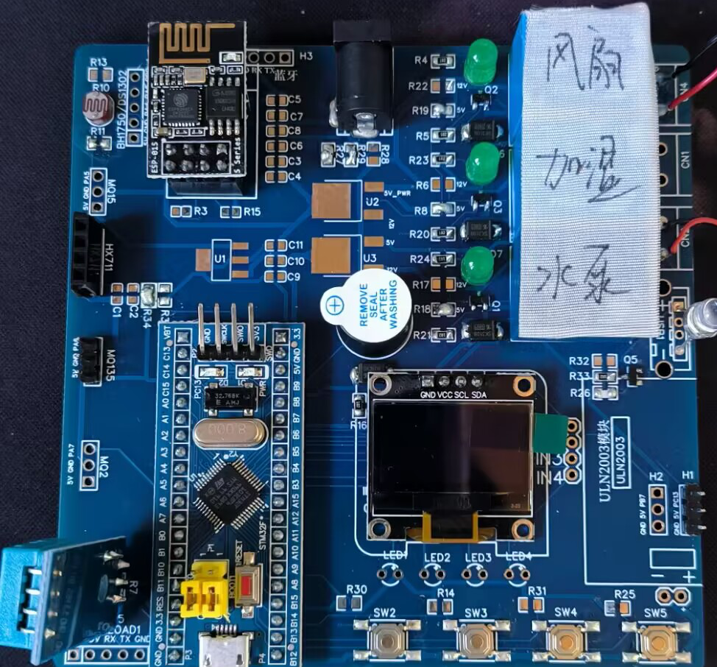
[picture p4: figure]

图5-2 PCB实物图

## 5.2 电路板上电调试

### 5.2.1 供电测试

硬件测试主要涵盖以下方面：OLED显示屏、WiFi模块、传感器数据采集模块、阈值设置和超出阈值后各驱动模块是否能按照设计要求驱动功能验证。

首先先进行电路板供电测试，为了避免线路短路损坏元器件，已经在上一步进行过线路检查。现在，将使用充电宝的5V供电口进行供电，并利用AMS1117稳压芯片将5V电压转换为3.3V电压[34]。同时，使用万用表对电路电压进行测量。当供电后电路板上各元器件工作正常。STM32单片机供电理论电压3.3V，实际测量电压3.29V，测量结果在误差范围之内，满足设计要求。测量结果如下图5-3所示。

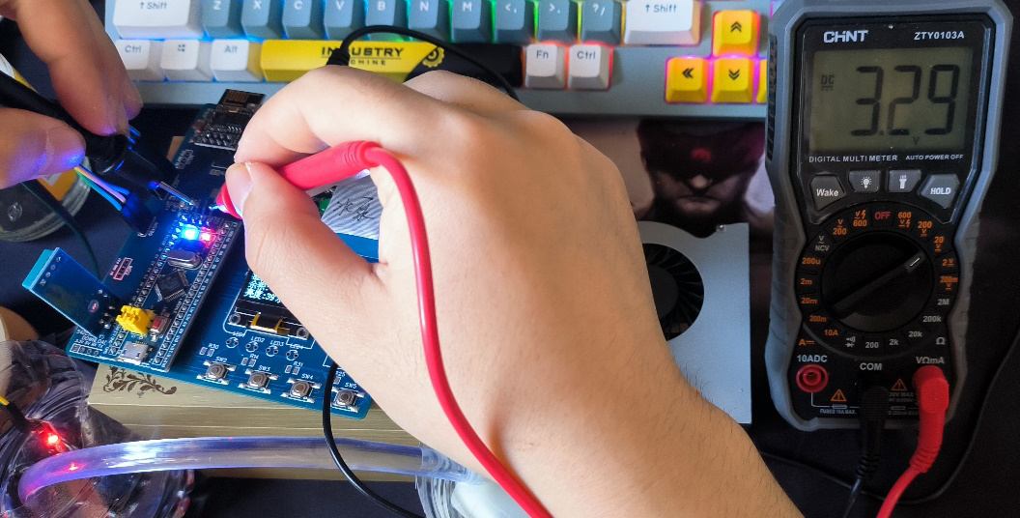
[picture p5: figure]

图5-3 供电测试

### 5.2.2 传感器数据采集功能测试

整个系统设计共包含以下几种传感器：温湿度传感器，水位传感器，压力传感器，光照传感器。在系统完成上电工作并运行一段时间后，各传感器将采集环境温度，湿度，水位，食物重量，光照强度等信息传送到物联网云平台，然后传输到手机端APP实时监测，同时也将在OLED屏幕上显示。测试结果如下图5-4所示。

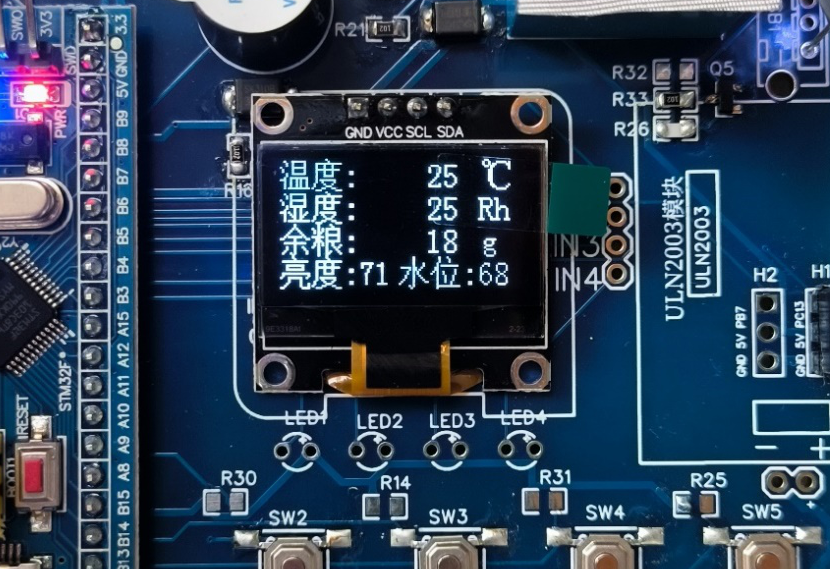
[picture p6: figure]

图5-4 传感器数据采集功能测试

### 5.2.3 驱动部分功能测试

驱动部分包括以下几个模块：风扇，加湿器，水泵，舵机，LED灯。当传感器数据采集功能正常运行后，进行下一步测试也就是驱动部分的功能验证，将电路板供电运行一段时间后，人为改变环境各数据，记录OLED屏幕显示的数据信息，并观察驱动部分相应动作，进行四组测试，系统阈值设定统一为：温度25℃，湿度60Rh，余粮5g，水位20。测试结果如表5-1所示。

表5-1 驱动部分测试结果

名称 | 第一组 | 第二组 | 第三组 | 第四组
温度 | 19℃ | 28℃ | 30℃ | 33℃
湿度 | 36Rh | 49Rh | 68Rh | 43Rh
水位 | 33 | 66 | 7 | 21
余粮 | 2g | 13g | 4g | 9g
光强 | 88 | 66 | 49 | 20
风扇 | 关闭 | 开启 | 开启 | 开启
加湿器 | 开启 | 开启 | 关闭 | 开启
水泵 | 关闭 | 关闭 | 开启 | 关闭
舵机 | 转动90° | 静止 | 转动90° | 静止
LED灯 | 较暗 | 暗 | 亮 | 较亮

根据以上四组测试结果可以得出驱动部分各模块工作正常，满足设计要求。另外可以通过四个按键SW2、SW3、SW4、SW5改变温湿度阈值以及控制LED灯的开关，在SW5按键按下后灯熄灭，再次按下灯亮，SW5按键工作正常。然后在表5-1中第二组的数据下通过按键改变温湿度阈值进行四组测试，测试结果如下表5-2所示。

表5-2 按键测试结果

名称 | 第一组 | 第二组 | 第三组 | 第四组
温度阈值 | 25℃ | 20℃ | 20℃ | 30℃
湿度阈值 | 60Rh | 45Rh | 65Rh | 55Rh
风扇 | 开启 | 开启 | 开启 | 关闭
加湿器 | 开启 | 关闭 | 开启 | 开启

## 5.3 软件部分调试

### 5.3.1 设备接入OneNET云平台测试

设备上电之后，可以正常工作，数据显示正常，现在进行WiFi连接，发现WiFi模块一直无法连接到手机热点，仔细检查代码后并无问题，在经过网上查找资料后找到了原因：ESP8266目前只能接受2.4Ghz的信号，而手机热点可以选择2.4G和5G，将手机热点频段改为2.4G后连接成功。如下图5-5所示。

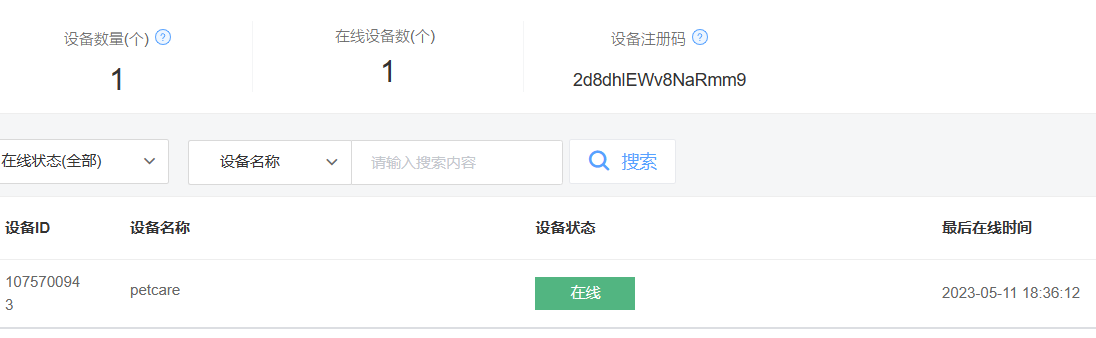
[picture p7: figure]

图5-5 设备在线记录

### 5.3.2 数据流监测

设备成功连接到OneNET云平台后，设备需要按照指定格式发送数据才能被平台接收。一旦平台成功接收到设备发送的数据包，用户可以在网页控制台或手机APP中查看数据流。这些数据流的名称是由单片机在上传数据时定义的。其中temperature和humility为温湿度传感器dht11测量的环境温湿度值，范围为0-100，单位分别为“℃”和“Rh”。shuiwei为水位传感器Water Sensor测量的数值，范围为0-100。yuliang为压力传感器HX711测量的数值，范围为0-50，单位为“g”。light为光照传感器测量的光照强度数值，范围为0-100。并且每个数据流可以根据不同时间段对测量数据进行详细的查看。比如点开light的数据流详情，可以看到每个时间段对应的光照强度大小。具体数据流数据查看如下图5-6所示

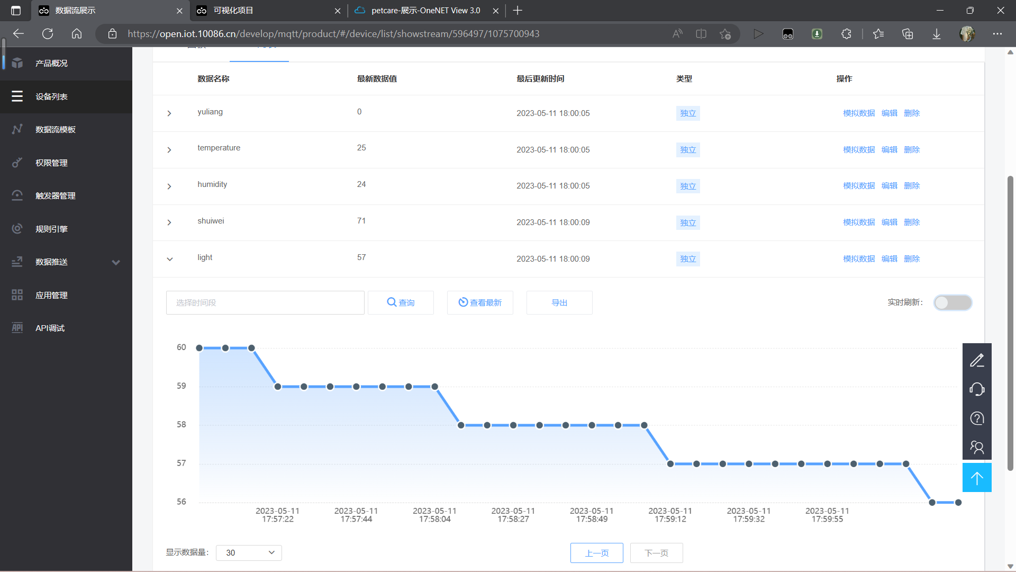
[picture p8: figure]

图5-6 网页端数据流显示图

手机端使用OneNET附带的APP设备云也可以进行监测，首先使用OneNET账号登录后，便可进行查看，如下图5-7所示。

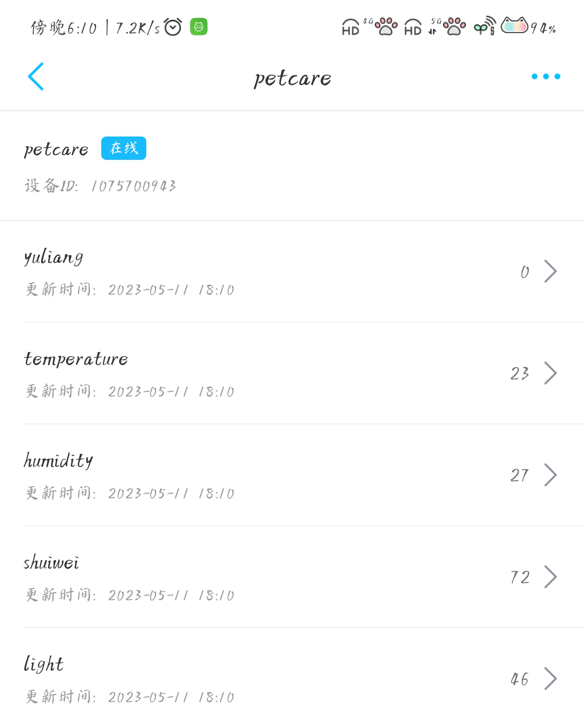
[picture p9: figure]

图5-7 手机端数据流显示图

在获取数据后，还可以通过OneNET物联网云平台的数据可视化服务将采集到的数据用图表的方式实时展现出来，便于更清楚更简单的查看相应的数据。可以自由编辑页面，可以选择网页类型：电脑页面或者移动端页面，这里选择创建一个电脑页面。然后选择使用仪表盘分别展示温度、湿度、水位、余粮和光照的实时大小，并用折线图显示这些数据的变化情况。制作完成效果如下图5-8所示。

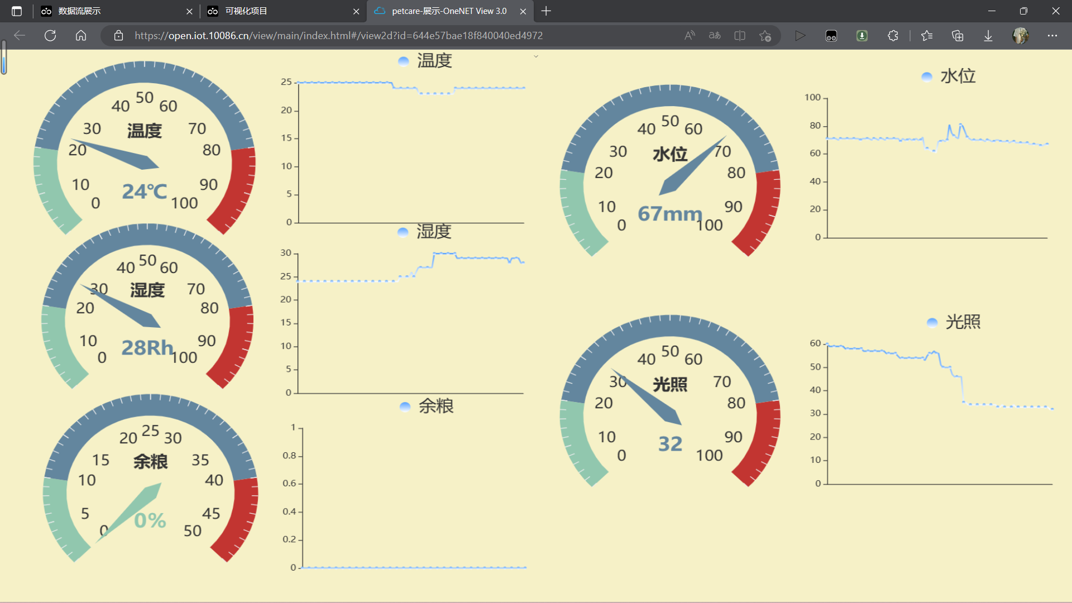
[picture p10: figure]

图5-8 数据可视化页面

在制作完成后还可以将制作的此项目发布，可以随时随地通过链接访问上述创建的数据可视化页面。

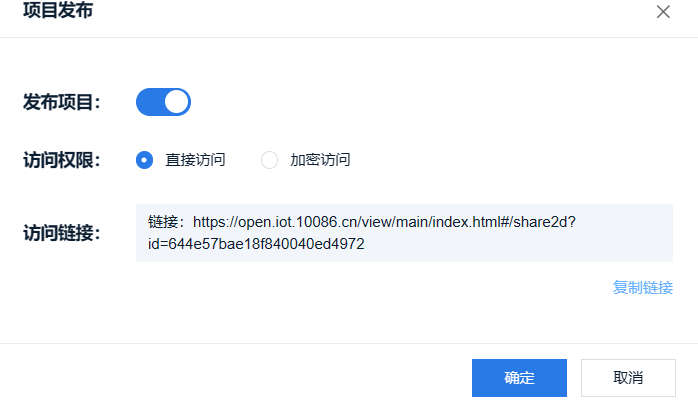
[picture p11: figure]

图5-9 项目发布

### 5.3.3 客户端远程控制测试

经过上面的各种调试，已经基本实现了设计要求，最后调试一下使用OneNET网页端远程下发指令控制设备实现相应动作，如下图5-10所示。下发命令对应的动作已经在上文的表4-1信号指令表中说明，这里不再赘述。

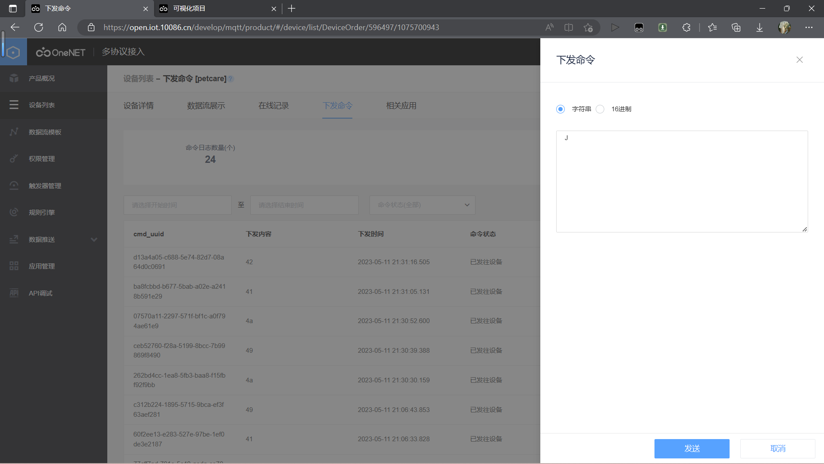
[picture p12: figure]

图5-10 下发命令页面

在调试过程中发现设备连接后下发命令，ESP8266指示灯闪烁表示WiFi模块已经接受到指令，但是设备并无响应，经过多次调试与检查后发现需要先下发命令“J”关闭自动模式后，再下发其他指令才可进行远程控制。下发指令“I”再次开启自动模式。将此问题弄清楚后，调试成功，进行了多次测试，设备均可准确运行。

到此整个设备调试完成，达到预期设计目标。

# 第6章 经济分析与环保分析

## 6.1 经济性分析

物联网智能宠物看护系统具有多项经济性优势。

首先，该系统可以通过智能化的监控和控制，降低照料宠物的成本。传统的宠物看护方式需要雇佣专业人员或者将宠物送到宠物店进行照料，这些方式都需要花费一定的费用。而智能宠物看护系统则可以通过智能喂食、自动换水等功能，降低了雇佣专业人员的成本，并且可以减少宠物寄养的费用。

其次，该系统可以提高宠物的健康水平，从而减少兽医费用。智能宠物看护系统可以通过实时监测宠物的饮食、生活环境各项数据，及时发现宠物的问题并采取相应的措施，从而减少宠物生病的概率。这样不仅可以降低兽医费用，还可以延长宠物的寿命，进一步降低了养宠物的成本。

第三，该系统可以提供更好的用户体验，增加用户黏性和忠诚度。智能宠物看护系统可以通过手机App等方式提供实时监控，让宠物主人能够随时随地监控宠物的情况，并及时做出相应的调整。这种个性化的服务可以提高用户的满意度，增加用户对产品的依赖和信任。

综上所述，物联网智能宠物看护系统具有多项经济性优势，可以降低成本，提高用户体验，是一项非常具有投资价值的技术。

## 6.2 环保性分析

能耗方面：使用的STM32芯片本身具有低功耗特点而且同时还保证了系统整体的正常运行，因此，整个系统有着很高的能耗比。

使用寿命：物联网智能宠物看护系统的寿命也是影响其环保性的因素之一。如果系统寿命较短，将会增加更新和更换的频率，导致更多的废弃物和资源浪费。因此，在设计系统时考虑到其长久的使用寿命，使用PCB打板代替普通洞洞板焊接，使得电路板的使用寿命大大延长。

健康安全：物联网智能宠物看护系统在使用中符合健康安全标准，不会对人和宠物造成伤害和危害。使用的是环保材料元件，以确保系统安全环保。

# 结 论

本文基于一款STM32单片机，使用多种传感器检测各项数据，在OLED屏幕上显示的同时将这些数据通过ESP8266模块上传到OneNET物联网云平台，可以在网页端实时监测也可以在手机APP上远程监测。系统设计有两种工作模式，自动模式下单片机会将数据与阈值比较，然后给驱动模块相应信号，使其做出相应动作。手动模式需要通过物联网平台先下发命令关闭自动模式，之后便可通过下发不同的命令信号控制驱动模块。

经过硬件电路设计和软件设计，成功完成了实物的制作以及调试工作。基本上能够实现远程看护宠物的要求，并且经济成本较低，微型化，低能耗能够广泛应用，传感器测量结果误差小，可靠性高，物联网技术迎合当前热门行业，具有广阔的发展空间。

由于时间原因和个人精力原因未能够做到完美，我认为还可以从以下几个方面进行改进和完善：

1. 不能监测宠物的运动轨迹，在后期研究可以加入定位功能或者加入摄像头实时监测宠物的状态。
2. 由于时间原因，硬件电路整体是无遮盖的，后续可以进行外观设计，3D打印一套外壳，使其更加美观实用。

# 参考文献

[1] 邵彦达，沈睿，眭耀宇.基于AT89C51单片机的智能宠物家居[J]. 科技创新导报，2017，14(14)：1-2.
[2] 周锦荣，张振宇，袁忠强.家居宠物智能喂食管理控制系统设计与应用[J]. 家畜生态学报，2019，40(04)：77-80.
[3] 吴明泽，胡立夫，胡家瑞，等.智能宠物护理机器人[J]. 中国科技信息，2021，(06)：79-80.
[4] 王凝.关于宠物喂食器的智能化发展趋势及设计方案研究[J]. 科技与创新，2022，(11)：93-95.
[5] Kim Seungcheon.Smart Pet Care System using Internet of Things[J]. International Journal of Smart Home，2016，10(3)：164-166.
[6] Anggraini Nenny，Rahman Dzul Fadli，Wardhani Luh Kesuma，et al.Mobile based monitoring system for an automatic cat feeder using Raspberry Pi[J]. TELKOMNIKA (Telecommunication Computing Electronics and Control)，2020，18(2)：354-357.
[7] 张帅，张迪，樊京，等.基于阿里云的电动汽车无线充电监控系统设计[J]. 电工技术，2021，(01)：102-104.
[8] 李雪健，陈燕春，夏文倩，等.黑板自动除尘系统[J]. 电子技术与软件工程，2022(20)：71-74.
[9] 张一波，董增寿，常春波.基于STM32F4的换热站控制系统的设计[J]. 太原科技大学学报，2021，42(06)：434-440.
[10] 迪力阿热木·吐尔地玉苏甫，郭斌.基于目标检测的自动断电实验台控制器的设计[J]. 电脑知识与技术，2022，18(18)：80-82+85.
[11] Biotechnology Companies; IAR Systems supports the new STM32 F0 low-cost ARM(R) CortexTM-M0 microcontrollers from STMicroelectronics(R)[J]. Technology & Business Journal，2012：67-70.
[12] Ganssle， Jack G.Watchdogs redux[J]. Embedded Systems Design，2011，24(2)：261-265.
[13] 魏永生.STM32单片机定时数据采集系统参数设置与编程[J]. 电子元器件与信息技术，2022，6(03)：23-25+28.
[14] 詹治国，林少波，郭栋，等.智慧楼宇通信技术架构及关键技术研究[J]. 计算机测量与控制，2022，30(12)：175-179+217.
[15] 孔祥斌. 某产品水下运动姿态测量系统设计[D]. 中北大学，2014：18-19.
[16] 张桂莲，石宜金，谭贵生，等.基于点灯科技的智能家居控制系统设计[J]. 现代信息科技，2023，7(08)：185-188.
[17] 沈晨航，周俊.基于ESP8266WiFi模块和MQTT协议的游泳馆水质监测系统设计[J]. 数字技术与应用，2020，38(05)：148-151.
[18] 史艳红，张玉杰.基于ZigBee和LabVIEW的多地无线温湿度监测系统设计[J]. 机床与液压，2015，43(22)：131-134.
[19] 王娇娇，田歌，王巧华，等.一体式禽蛋呼吸检测装置设计与试验[J]. 食品科技，2023，48(01)：50-55.
[20] 周乃迅，董文志，邓航宇.基于STC89C52的单手式水果称重采摘器研究[J]. 南方农机，2019，50(17)：27-28.
[21] Sawicka Marta J，Wróblewska Elwira K.The application of 7H-indolo[1，2-a]quinolinium merocyanine as a new water sensor in organic solvents.[J]. Chemicke zvesti，2018，72(3)：78-82.
[22] 骆雪汇，纪正辉，覃沛泳，等.微生态花园控制系统设计[J]. 机电信息，2023(06)：46-49.
[23] 朱磊，李辉，李广政，等.一种新型智能晾衣架系统设计[J]. 船电技术，2023，43(02)：38-41.
[24] 陈长征，窦宝茹，师亮.基于STM32单片机的智能停车场车位管理系统的设计与实现[J]. 西安航空学院学报，2020，38(05)：60-64.
[25] 蒋丹.识别“八大元件”的快捷技法[J]. 职业，2006(S1)：107-109.
[26] 宋锦.电子密码锁设计与调试[J]. 电脑知识与技术，2011，7(33)：8218-8220.
[27] 周树勋. 小型无人直升机机载飞行控制系统研究与设计[D]. 上海交通大学，2012：16-19.
[28] 张伟涛，刘保菊.智能化蔬菜大棚的设计与实现[J]. 工业控制计算机，2023，36(05)：154-155+158.
[29] 黎扬，何适.基于CANoe MQTT节点仿真的T-Box远程功能自动化测试[J]. 汽车电器，2022(07)：91-92+95.
[30] Ali Jawad，Haseeb Zafar Mohammad. Improved End-to-end service assurance and mathematical modeling of message queuing telemetry transport protocol based massively deployed fully functional devices in smart cities[J]. Alexandria Engineering Journal，2023，72：547-549.
[31] 王红玉. OneNET云平台下基于WiFi的智能家居监控系统的设计与实现[D]. 内蒙古大学，2021：42-44.
[32] 李嘉明，冯建，廖明华，等.基于ESP32的电子秤系统设计[J]. 电脑知识与技术，2021，17(12)：216-219.
[33] 陈陈. 基于阿里云IoT平台的智能空调控制系的设计与实现[D]. 合肥工业大学，2021：61-65.
[34] Diaconu E.M..Electrical Device Control System Through Wi-Fi Technology[J]. The Scientific Bulletin of Electrical Engineering Faculty，2021，21(1)：407-408.

# 附录1 系统硬件电路图

# 附录2 系统部分程序代码

int main(void)

{

u8 a=0;

u8 val = 0;

Timer_SRD_Init(9998,7199);//time3 定时器初始化

NVIC_PriorityGroupConfig(NVIC_PriorityGroup_2);

delay_init();

OLED_Init();

LED_Init();

KEY_Init();

Adc_Init();

SG90_Init();

DHT11_Init();

TIM2_PWM_Init(100,719);

uart_init(115200);

uart2_init(115200);

WiFi_RxCounter=0; memset(WiFi_RX_BUF,0,WiFi_RXBUFF_SIZE); WiFi_ResetIO_Init();

u1_printf("U1 OK");

u2_printf("U2 OK");

SG90_angle(90);

delay_ms(100);

LED_AllOff();

BEEP_OFF;

RELAY1_OFF;

RELAY2_OFF;

RELAY3_OFF;

SG90_angle(0);

OLED_Clear();

Init_HX711pin();

delay_ms(100);

Get_Maopi();

delay_ms(100);

Get_Maopi();

delay_ms(100);

OLED_ShowCH(0,0,"温度:");

OLED_ShowCH(102,0,"℃");

OLED_ShowCH(0,2,"湿度:");

OLED_ShowCH(101,2,"%");

OLED_ShowCH(0,4,"余粮:");

OLED_ShowCH(102,4,"%");

OLED_ShowCH(0,6,"亮度:");

OLED_ShowCH(60,6,"水位:");

while(1){

if(strstr(WiFi_RX_BUF,"I"))

{

u1_printf(WiFi_RX_BUF);

auto_k1=1;

WiFi_RxCounter=0;

memset(WiFi_RX_BUF,0,WiFi_RXBUFF_SIZE);

}

if(strstr(WiFi_RX_BUF,"J"))

{

u1_printf(WiFi_RX_BUF);

auto_k1=0;

RELAY1_OFF;

RELAY2_OFF;

RELAY3_OFF;

WiFi_RxCounter=0; memset(WiFi_RX_BUF,0,WiFi_RXBUFF_SIZE); }

if(auto_k1==0)

{wifi_C();

if(sg90munber==0) SG90_angle(0);

if(sg90munber==90) SG90_angle(90);

delay_ms(100);

}

if(KEY1_IN_STA==0){

delay_ms(100);

if(KEY1_IN_STA==0){

val++ ;

OLED_Clear();

}

}

if(KEY4_IN_STA==0){

delay_ms(100);

if(KEY4_IN_STA==0){

light_onoff ++;

}

}

switch (val%3)

{case 0: if(a%10==0)

{get_shuju();

a=0;

}

break;

case 1: set_wendu();

break;

case 2: set_shidu();

break;

default: return 0;

}

if(auto_k1==1) auto_kongzhi();

}

}

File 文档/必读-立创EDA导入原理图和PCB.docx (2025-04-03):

# 1. 软件下载网址：

软件下载 - 嘉立创EDA (lceda.cn) (https://lceda.cn/page/download)

按照电脑配置下载对应的版本。并安装。

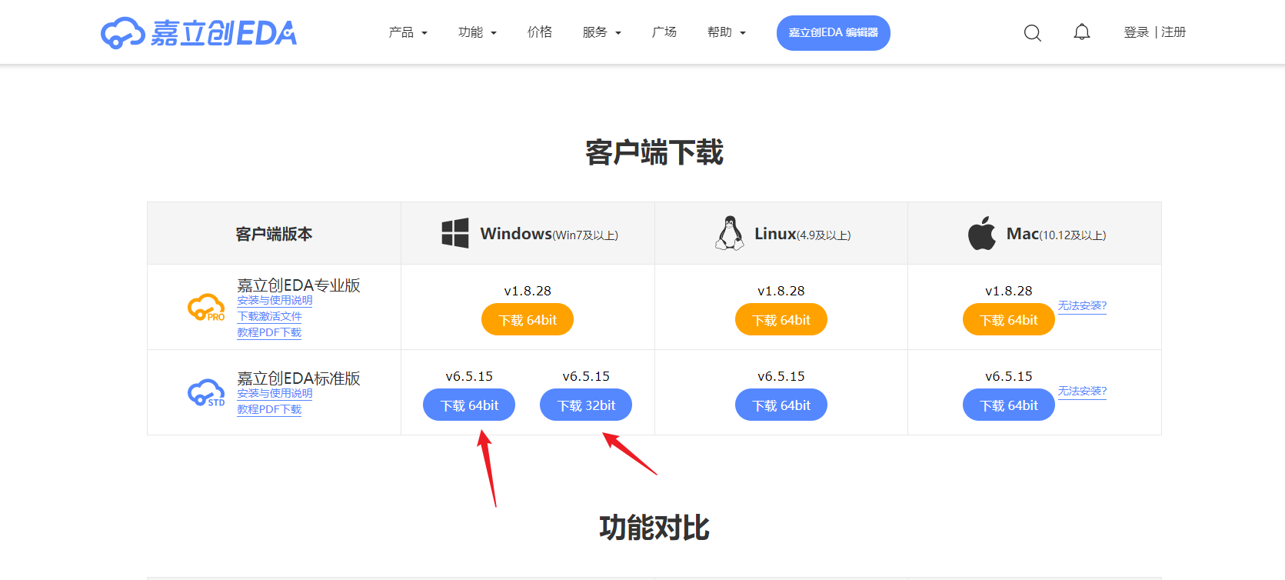
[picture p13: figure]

# 2. 导入原理图和PCB

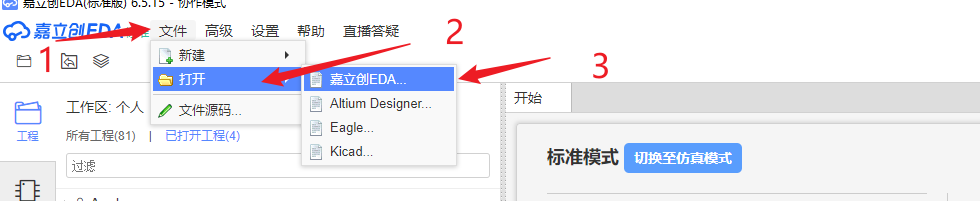
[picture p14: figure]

2.选择.json 文件打开

3.

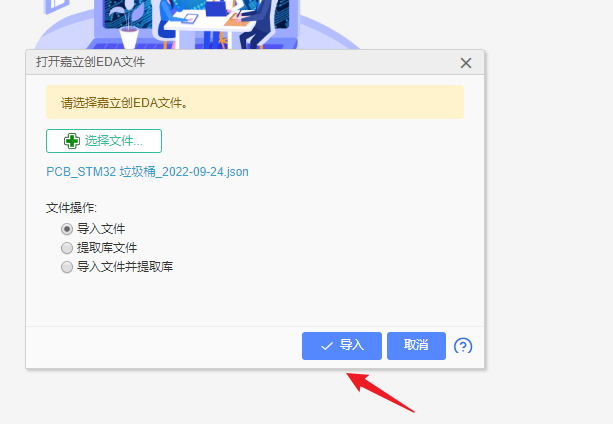
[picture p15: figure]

4.

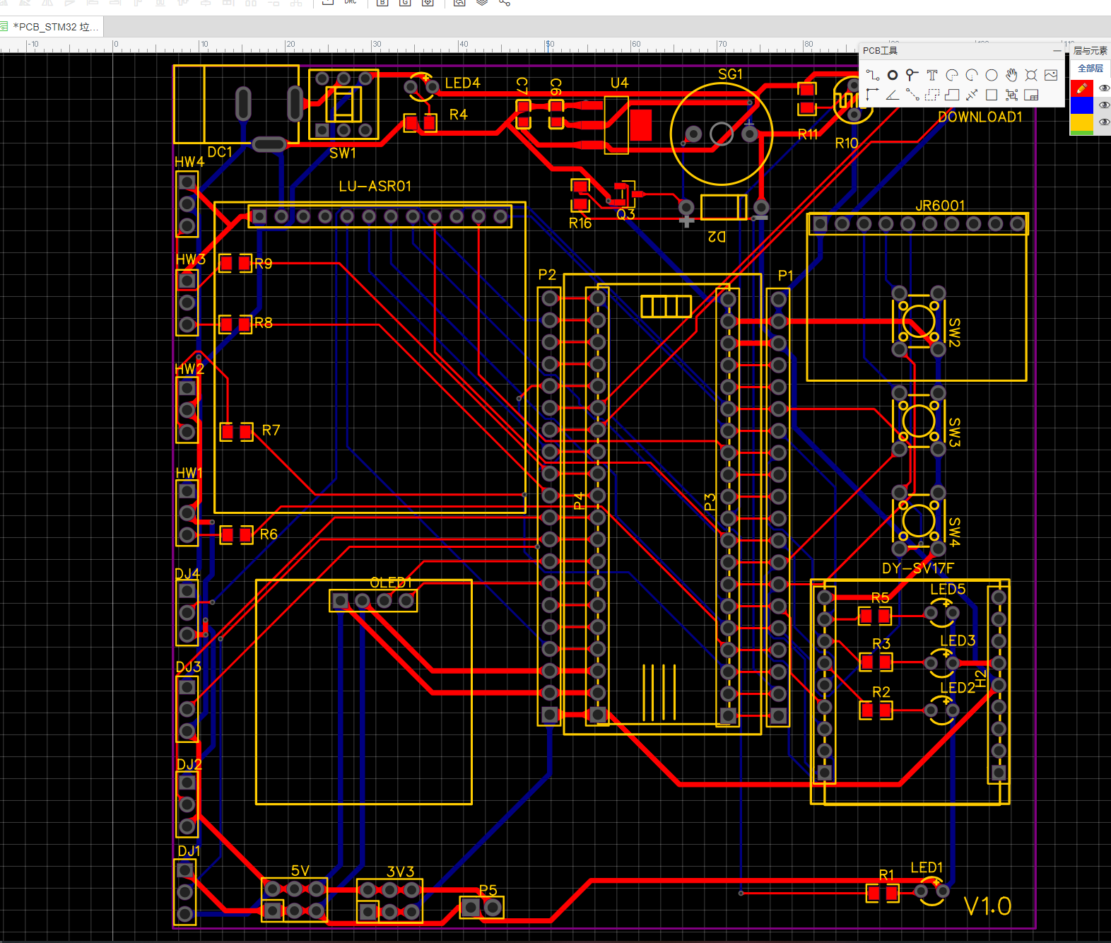
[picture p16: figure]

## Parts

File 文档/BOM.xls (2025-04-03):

ID | Name | Designator | Footprint | Quantity | Manufacturer Part | Manufacturer | Supplier | Supplier Part | Price
1 | Female header 2.54 1*5Ｐ | BH1750/DS1302,DOWNLOAD1 | HDR-TH_5P-P2.54-V-F | 2 | Female header 2.54 1*5Ｐ | ReliaPro | LCSC | C46341 | 0.254
2 | FMQ-BUZZER2 | BUZZER2 | BUZ-TH_BD12.0-P7.60-D0.6-FD | 1 | FMQ-BUZZER2 |  | LCSC | C9900006103
3 | 0.1UF | C1,C2,C3,C4,C5,C6,C7,C8,C9,C10,C11 | C0603 | 11
4 | 1N4734A_C238924 | D1,D2,D3,D4 | LL-41_L5.0-W2.5-RD | 4 | 1N4734A | ON Semicon | LCSC | C238924 | 0.4006
5 | DC-005-25A | DC1 | DC-IN-TH_DC005 | 1 | DC-005-25A | HRO | LCSC | C136715 | 0.7728
6 | Header 2.54_1x3 | DHT11,H1,H2,MQ2,MQ15,MQ135 | HDR-TH_3P-P2.54-V-M-1 | 6 | Header2.54mm 1*3P | BOOMELE | LCSC | C49257 | 0.0885
7 | ESP-01S_C503582 | ESP8266 | WIFIM-TH_8P-L24.7-W14.4-P2.54 | 1 | ESP-01S | Ai-Thinker | LCSC | C503582 | 14.16
8 | HX711 | HX711 | HDR-TH_4P-P2.54-V-F | 1 | Female header1*4P | BOOMELE | LCSC | C66508 | 0.3978
9 | JQC-3FF/05-1ZS(551) | K1,K2,K3 | RELAY-TH_HF3FF-XX-1ZXX-XXX | 3 | JQC-3FF/05-1ZS(551) | HF | LCSC | C9221 | 2.68
10 | 264-7SURT/S530-A3 | LED1,LED2,LED3,LED4,LED5,LED6,LED7 | LED-TH_BD3.2-P2.54-RD | 7 | 264-7SURT/S530-A3 | Everlight Elec | LCSC | C710207 | 0.3129
11 | 0.96OLED_4P_MODULE_JX | OLED1 | 0.96OLED_4P | 1 | 0.96OLED_4P_MODULE_JX | null | LCSC | C9900004566
12 | FHT9014Y-ME | Q1,Q2,Q3,Q4,Q5 | SOT-23-3_L2.9-W1.3-P1.90-LS2.4-BR | 5 | FHT9014Y-ME | FH | LCSC | C88861 | 0.107
13 | 1K | R1,R2,R4,R9,R12,R23,R24 | 805 | 7 | RMC08051K5%N | Tyohm | LCSC | C269727 | 0.0259
14 | 0R | R3 | R0603 | 1
15 | 2k | R5,R20,R21 | 805 | 3 | RMC08051K5%N | Tyohm | LCSC | C269727 | 0.0259
16 | 0R | R6,R8,R17,R18,R19,R22,R29,R34 | 805 | 8 | RMC08051K5%N | Tyohm | LCSC | C269727 | 0.0259
17 | 10K | R7,R11,R14,R25,R30,R31 | 805 | 6 | RMC08051K5%N | Tyohm | LCSC | C269727 | 0.0259
18 | GL5539 | R10 | RES-TH_L5.1-W4.3-P3.40-D0.5 | 1 | GL5539 | Senba | LCSC | C125630 | 0.2673
19 | NC/0R | R13,R27,R28,R32,R35 | 805 | 5 | RMC08051K5%N | Tyohm | LCSC | C269727 | 0.0259
20 | 220R | R15 | R0603 | 1
21 | 1k | R16,R26,R33 | 805 | 3 | RMC08051K5%N | Tyohm | LCSC | C269727 | 0.0259
22 | K2-1102DP-A4SW-04 | SW2,SW3,SW4,SW5 | SW-SMD_4P-L6.0-W6.0-P4.50-LS10.0-BL | 4 | K2-1102DP-A4SW-04 | Korean Hroparts Elec | LCSC | C223769 | 0.2809
23 | AMS1117-3.3_C2992570 | U1,U4 | SOT-223-3_L6.4-W3.5-P2.30-LS7.0-BR | 2 | AMS1117-3.3 | 国芯佳品 | LCSC | C2992570 | 0.3061
24 | AS7805ADTR-E1 | U2,U3 | TO-252-2_L6.6-W6.1-P4.57-LS9.9-BR-CW | 2 | AS7805ADTR-E1 | Diodes Incorporated | LCSC | C127926 | 0.7886
25 | STM32最小系统 | U6 | STM32最小系统板C8T6 | 1
26 | USB-A-F-180-H20.5 | USB1 | USB-A-TH_C168710 | 1 | 916-151A101DY10200 | 精拓金 | LCSC | C168710 | 1.1085

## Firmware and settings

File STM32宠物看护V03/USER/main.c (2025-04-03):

/*
key  PB0 PB1 PB12 PB11 	ok
beep PA8 								ok
水位 PA6					 			OK
光照 PA5 								OK
继电器 PA12 PA11  PB8 	OK
WIFI PA1 PA2 PA3 				OK
OLED PB5 PB6 						OK
舵机	PC13							OK

DHT11  PB11  					待调试
LIGHT  PA0						待调试
HX711称重  PB3 PB4		待调试
*/

#include "sys.h"  
#include "delay.h"
#include "oled_iic.h"
#include "stdio.h"
#include "wave.h"
#include "timer.h"
#include "ds18b20.h" 
#include "key.h"        //包含需要的头文件
#include "led.h"        //包含需要的头文件
#include "usart22.h"
#include "stdbool.h"
#include <stdio.h>  
#include <string.h>  
#include "usart.h"	
#include "DHT11.h"
#include "HX711.h"


//=======================================================================
#define WiFi_RX_BUF     USART2_RX_BUF       //串口1控制 WiFi
#define WiFi_RXBUFF_SIZE  USART2_REC_LEN  //串口1控制 WiFi
#define WiFi_RxCounter    USART2_RX_STA    //串口1控制 WiFi
char *str1;							//wifi

int time1=0,time2=0,time3=0;
u8 set_mark1=0,automark=0;
short Temp1set=30,Humi1set=60;
short temperature;   
char databuff[64];          //缓冲区
u8 set_mark=0;
extern u8 DHT11Data[4];//温湿度数据(温度高位,温度低位,湿度高位,湿度低位)
int Temp1,Humi1,light_pa5,shuiwei_pa6,shuiwei_pa7;   // ADC的值 光照 PA5 水位PA6  水位2 PA7
extern s32 Weight_Shiwu; //称重的数量
int i,sg90munber=0;	
int  adcdata[3];          //用于保存3个ADC通道的数据	  保存水位值	
u8 light_onoff = 1;
short auto_k1=1,auto_k2=1,auto_k3=1,auto_k4=1;
int onenet_time=0;


void get_shuju() //收集数据，上传云端
{
		OLED_ShowCH(0,0,"温度:");		//测试显示中文
		OLED_ShowCH(102,0,"℃");		//测试显示中文
		OLED_ShowCH(0,2,"湿度:");		//显示中文：温度		
		OLED_ShowCH(101,2,"Rh");		//显示：℃	
		OLED_ShowCH(0,4,"余粮:");		//测试显示中文
		OLED_ShowCH(102,4,"g");		//测试显示中文
		OLED_ShowCH(0,6,"亮度:");		//显示中文：温度		128*64
		OLED_ShowCH(60,6,"水位:");		//显示中文：温度	
	 			
		
		Get_Weight(); //获取重量
onenet_time++;

		OLED_ShowNum(50,4,Weight_Shiwu/50,5,0);	  //显示重量
	 
//********************adc获取light  shuiwei**********************************************	
		for(i=0;i<3;i++){
	  adcdata[i] = (Get_Adc_Average(i+5,10));
		}
		light_pa5 = 100-adcdata[0]/41;  //最大4095   该公式控制亮度值为0~100
		shuiwei_pa6 =adcdata[1]/41;    //最大4095   该公式控制水位的值为0~100
		shuiwei_pa7 =adcdata[2];		//200时表示水位很满，80以下为缺水不
	 
		
//		u1_printf("Temp1: %d ",Temp1);	
//		u1_printf("Humi1: %d ",Humi1);		
//		u1_printf("Weight_Shiwu: %d ",Weight_Shiwu);		
//===========================上传云端=========================================================================
//    sprintf(databuff,"{\"temperature\":%d,\"humidity\":%d,\"yuliang\":%d,\"light\":%d,\"shuiwei\":%d}",Temp1,Humi1,Weight_Shiwu/45,light_pa5,shuiwei_pa6);   //构建数据
  
	if(onenet_time==10)
		{	
		onenet_time=0;			
		sprintf(databuff,"{\"light\":%d,\"shuiwei\":%d}",light_pa5,shuiwei_pa6);   //构建数据		
		u2_printf(databuff);	
		}
}

void set_wendu() //设置温度
{
	if(KEY2_IN_STA==0){                  //+5
		delay_ms(100);                     
		if(KEY2_IN_STA==0){              
				Temp1set = Temp1set+5;						
		}
	}
	if(KEY3_IN_STA==0){                  //-5
		delay_ms(100);                     
		if(KEY3_IN_STA==0){              
			Temp1set = Temp1set-5;
			if(Temp1set<=0)Temp1set=0;			
		}
	}
		OLED_ShowCH(0,0,"温度:");		//显示中文：温度	
		OLED_ShowCH(101,0,"℃");		//显示：℃
		OLED_ShowNum(50,0,Temp1set,5,0);
		OLED_ShowCH(0,3,"设置模式");		//显示中文：温度	
}

void set_shidu() //设置湿度
{
	if(KEY2_IN_STA==0){                  //+5
		delay_ms(100);                     
		if(KEY2_IN_STA==0){              
				Humi1set = Humi1set+5;						
		}
	}
 
}

void auto_kongzhi()
{ 
	if(Humi1<Humi1set)RELAY2_ON;//湿度控制
	else RELAY2_OFF;
	 
}


void wifi_C()
{
		if(strstr(WiFi_RX_BUF,"A"))  
		{
			u1_printf(WiFi_RX_BUF);
		auto_k1=0;RELAY1_ON;
			
			WiFi_RxCounter=0;                               //WiFi接收数据量变量清零  
			memset(WiFi_RX_BUF,0,WiFi_RXBUFF_SIZE);         //清空WiFi接收缓冲区 
		}			
		if(strstr(WiFi_RX_BUF,"B"))  
		{
			u1_printf(WiFi_RX_BUF);
		auto_k1=0;RELAY1_OFF;
			
			WiFi_RxCounter=0;                               //WiFi接收数据量变量清零  
			memset(WiFi_RX_BUF,0,WiFi_RXBUFF_SIZE);         //清空WiFi接收缓冲区 
		}	
		if(strstr(WiFi_RX_BUF,"C"))  
		{
			u1_printf(WiFi_RX_BUF);
		auto_k1=0;RELAY2_ON;
			
			WiFi_RxCounter=0;                               //WiFi接收数据量变量清零  
			memset(WiFi_RX_BUF,0,WiFi_RXBUFF_SIZE);         //清空WiFi接收缓冲区 
		}	
		if(strstr(WiFi_RX_BUF,"D"))  
		{
			u1_printf(WiFi_RX_BUF);
		auto_k1=0;RELAY2_OFF;
			
			WiFi_RxCounter=0;                               //WiFi接收数据量变量清零  
			memset(WiFi_RX_BUF,0,WiFi_RXBUFF_SIZE);         //清空WiFi接收缓冲区 
		}	
		if(strstr(WiFi_RX_BUF,"E"))  
		{
			u1_printf(WiFi_RX_BUF);
		auto_k1=0;RELAY3_ON;
			
			WiFi_RxCounter=0;                               //WiFi接收数据量变量清零  
			memset(WiFi_RX_BUF,0,WiFi_RXBUFF_SIZE);         //清空WiFi接收缓冲区 
		}	
		 
}


int main(void)
{		
	u8 a=0;	
	
	u8 val = 0;
	Timer_SRD_Init(9998,7199);//time3  定时器初始化
//	TIM4_Int_Init(4999,20000);// time4 倒计时中断1s   10Khz的计数频率，计数到5000为500ms  	65536  
	NVIC_PriorityGroupConfig(NVIC_PriorityGroup_2);//设置中断优先级分组为组2：2位抢占优先级，2位响应优先级
	
	delay_init();
	OLED_Init();		 	//OLED屏幕初始化		
	LED_Init();	                    //LED初始化  dht11初始化 BEEP初始化 WIFI
	KEY_Init();  	//按键初始化
	 uart_init(115200);	  // DEBUG
	uart2_init(115200);  //onenet串口初始化为115200	  //	uart2_init(9600);  //蓝牙9600

	WiFi_RxCounter=0;                               //WiFi接收数据量变量清零  
	memset(WiFi_RX_BUF,0,WiFi_RXBUFF_SIZE);         //清空WiFi接收缓冲区 	
	WiFi_ResetIO_Init();														//wifi
	
		
		
	u1_printf("U1 OK");
	u2_printf("U2 OK");
	SG90_angle(90);
//	LED_AllOn();
//	BEEP_ON;
//	RELAY1_ON;	
//	RELAY2_ON;
//	RELAY3_ON;
	delay_ms(100);
	LED_AllOff();
	BEEP_OFF;
	RELAY1_OFF;	
	RELAY2_OFF;
	RELAY3_OFF;
	SG90_angle(0);		
	OLED_Clear();	
	//while(Wave_SRD_Strat(t)); //超声波初始化
	
	Init_HX711pin();			//HX711 称重模块初始化 一定要最后一个初始化
	delay_ms(100);	
	Get_Maopi();				//HX711  称毛皮重量
	delay_ms(100);	
	Get_Maopi();				//HX711  称毛皮重量	
	delay_ms(100);		
	
	 
		OLED_ShowCH(0,4,"余粮:");		//测试显示中文
		OLED_ShowCH(102,4,"%");		//测试显示中文
		OLED_ShowCH(0,6,"亮度:");		//显示中文：温度		128*64
		OLED_ShowCH(60,6,"水位:");		//显示中文：温度			
	
	
	
while(1){
//==============物联网控制==================
if(strstr(WiFi_RX_BUF,"I"))  		//开启自动控制
{
	u1_printf(WiFi_RX_BUF);
	auto_k1=1;
	
	WiFi_RxCounter=0;                               //WiFi接收数据量变量清零  
	memset(WiFi_RX_BUF,0,WiFi_RXBUFF_SIZE);         //清空WiFi接收缓冲区 
}			
if(strstr(WiFi_RX_BUF,"J"))  //关闭自动控制
{
	u1_printf(WiFi_RX_BUF);
	auto_k1=0;
	RELAY1_OFF;	
        //WiFi接收数据量变量清零  
	memset(WiFi_RX_BUF,0,WiFi_RXBUFF_SIZE);         //清空WiFi接收缓冲区 
}
if(auto_k1==0)	
{wifi_C();					

if(sg90munber==0)		SG90_angle(0);
if(sg90munber==90)		SG90_angle(90);

	delay_ms(100);
}//==============物联网控制==================	



	if(KEY1_IN_STA==0){                  //设置阈值选项
	delay_ms(100);                     
	if(KEY1_IN_STA==0){              
			val++ ;	
			OLED_Clear();			
		}
	}
	
	if(KEY4_IN_STA==0){                  //灯光控制
	delay_ms(100);                     
	if(KEY4_IN_STA==0){              
			light_onoff ++;		
		}
	}	
	
    switch (val%3)
    {
        case 0:
            if(a%10==0)
						{
							get_shuju();
							a=0;
						}
            break;
      
        default: return 0;
    }
	if(auto_k1==1)	auto_kongzhi();			//自动控制函数
//	delay_ms(1);
	a++;
		
	
}
}

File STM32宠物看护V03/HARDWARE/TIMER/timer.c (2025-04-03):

#include "timer.h"
//#include "sys.h"
//初始化定时器
void Timer_SRD_Init(u16 arr,u16 psc)
{
	TIM_TimeBaseInitTypeDef TIM_BaseInitStruct;
	NVIC_InitTypeDef NVIC_InitStruct;
	
	RCC_APB1PeriphClockCmd(RCC_APB1Periph_TIM3,ENABLE);
	
	TIM_BaseInitStruct.TIM_CounterMode=TIM_CounterMode_Up;
	TIM_BaseInitStruct.TIM_Period=arr;
	TIM_BaseInitStruct.TIM_Prescaler=psc;
	TIM_BaseInitStruct.TIM_ClockDivision=0;
	TIM_TimeBaseInit(TIM3,&TIM_BaseInitStruct);
	//中断优先级管理
	NVIC_InitStruct.NVIC_IRQChannel=TIM3_IRQn;
	NVIC_InitStruct.NVIC_IRQChannelCmd=ENABLE;
	NVIC_InitStruct.NVIC_IRQChannelPreemptionPriority=2;
	NVIC_InitStruct.NVIC_IRQChannelSubPriority=1;
	NVIC_Init(&NVIC_InitStruct);
	//开启更新中断，触发中断
	TIM_ITConfig(TIM3,TIM_IT_Update,ENABLE);
	TIM_ITConfig(TIM3,TIM_IT_Trigger,ENABLE);
	
	TIM_Cmd(TIM3,ENABLE);//使能中断
	
}
//中断服务函数
void TIM3_IRQHandler(void)
{
	if(TIM_GetITStatus(TIM3,TIM_IT_Update)!=RESET)
	{
		TIM_ClearITPendingBit(TIM3,TIM_IT_Update);
	}
	
}


/**************************************************************************
PA0 做PWM输出 TIM2 CH1   https://blog.csdn.net/tongzuo1997/article/details/80963797
**************************************************************************/


void TIM2_PWM_Init(u16 arr,u16 psc)//PA0 做PWM输出
{  
	GPIO_InitTypeDef 		GPIO_InitStructure;
	TIM_TimeBaseInitTypeDef  	TIM_TimeBaseStructure;
	TIM_OCInitTypeDef  	        TIM_OCInitStructure;
 
	RCC_APB1PeriphClockCmd(RCC_APB1Periph_TIM2, ENABLE);	 //使能定时器2时钟
 	RCC_APB2PeriphClockCmd(RCC_APB2Periph_GPIOA, ENABLE);  	 //使能GPIO外设时钟
	
 
        //引脚功能配置
	GPIO_InitStructure.GPIO_Pin = GPIO_Pin_0 ; //TIM2_CH1 TIM2_CH2
	GPIO_InitStructure.GPIO_Mode = GPIO_Mode_AF_PP;          //复用推挽输出！！
	GPIO_InitStructure.GPIO_Speed = GPIO_Speed_50MHz;
	GPIO_Init(GPIOA, &GPIO_InitStructure);
 
        //初始化TIM2
	TIM_TimeBaseStructure.TIM_Period = arr;                     //设置在下一个更新事件装入活动的自动重装载寄存器周期的值
	TIM_TimeBaseStructure.TIM_Prescaler =psc;                   //设置用来作为TIMx时钟频率除数的预分频值 
	TIM_TimeBaseStructure.TIM_ClockDivision = 0;                //设置时钟分割:TDTS = Tck_tim
	TIM_TimeBaseStructure.TIM_CounterMode = TIM_CounterMode_Up; //TIM向上计数模式
	TIM_TimeBaseInit(TIM2, &TIM_TimeBaseStructure);             //根据TIM_TimeBaseInitStruct中指定的参数初始化TIMx的时间基数单位
	
	//初始化TIM2 Channel1、Channel2 PWM模式	 
	TIM_OCInitStructure.TIM_OCMode = TIM_OCMode_PWM2;           //选择定时器模式:TIM脉冲宽度调制模式2
 	TIM_OCInitStructure.TIM_OutputState = TIM_OutputState_Enable; //比较输出使能
	TIM_OCInitStructure.TIM_OCPolarity = TIM_OCPolarity_High;   //输出极性:TIM输出比较极性高
	TIM_OC1Init(TIM2, &TIM_OCInitStructure);                    //根据T指定的参数初始化外设TIM2 OC1
	//TIM_OC2Init(TIM2, &TIM_OCInitStructure);                    //根据T指定的参数初始化外设TIM2 OC2
 
	TIM_OC1PreloadConfig(TIM2, TIM_OCPreload_Enable);  //使能TIM2在CCR2上的预装载寄存器
	//TIM_OC2PreloadConfig(TIM2, TIM_OCPreload_Enable);  //使能TIM2在CCR2上的预装载寄存器
 
	TIM_Cmd(TIM2, ENABLE);  //使能TIM2
}
/*主函数使用手法
int main(void)
{
	unsigned int pulse = 0;
	NVIC_PriorityGroupConfig(NVIC_PriorityGroup_2);		//中断控制器分组设置 
	Delay_Init();						//Systick初始化，用于普通的延时 
	DelayMs(200);	//等待电源稳定
	TIM2_PWM_Init(100,719);					//720分频，72000_000/720 = 100Khz的计数频率，计数到100为1KHz
	while(1)
	{		
		pulse = 0;
		for(i = 0; i < 100;i ++)
		{
			pulse += 1;
			TIM_SetCompare1(TIM2, pulse) ;
			TIM_SetCompare2(TIM2, pulse) ;
			DelayMs(50);
		}
		
		for(i = 0; i < 100;i ++)
		{
			pulse -= 1;
			TIM_SetCompare1(TIM2, pulse) ;
			TIM_SetCompare2(TIM2, pulse) ;
			DelayMs(50);
		}
	}
 
}

原文链接：https://blog.csdn.net/tongzuo1997/article/details/80963797
*/

//**********************************************************************************************************************











//============================time2=========================================================
void TIM4_Int_Init(u16 arr,u16 psc)
{
    TIM_TimeBaseInitTypeDef  TIM_TimeBaseStructure;
	NVIC_InitTypeDef NVIC_InitStructure;

	RCC_APB1PeriphClockCmd(RCC_APB1Periph_TIM4, ENABLE); //时钟使能
	
	//定时器TIM4初始化
	TIM_TimeBaseStructure.TIM_Period = arr; //设置在下一个更新事件装入活动的自动重装载寄存器周期的值	
	TIM_TimeBaseStructure.TIM_Prescaler =psc; //设置用来作为TIMx时钟频率除数的预分频值
	TIM_TimeBaseStructure.TIM_ClockDivision = TIM_CKD_DIV1; //设置时钟分割:TDTS = Tck_tim
	TIM_TimeBaseStructure.TIM_CounterMode = TIM_CounterMode_Up;  //TIM向上计数模式
	TIM_TimeBaseInit(TIM4, &TIM_TimeBaseStructure); //根据指定的参数初始化TIMx的时间基数单位
 
	TIM_ITConfig(TIM4,TIM_IT_Update,ENABLE ); //使能指定的TIM4中断,允许更新中断

	//中断优先级NVIC设置
	NVIC_InitStructure.NVIC_IRQChannel = TIM4_IRQn;  //TIM4中断
	NVIC_InitStructure.NVIC_IRQChannelPreemptionPriority = 2;  //先占优先级0级
	NVIC_InitStructure.NVIC_IRQChannelSubPriority = 2;  //从优先级3级
	NVIC_InitStructure.NVIC_IRQChannelCmd = ENABLE; //IRQ通道被使能
	NVIC_Init(&NVIC_InitStructure);  //初始化NVIC寄存器


	TIM_Cmd(TIM4, ENABLE);  //使能TIMx					 
}
////定时器3中断服务程序
//void TIM4_IRQHandler(void)   //TIM4中断
//{
//	if (TIM_GetITStatus(TIM4, TIM_IT_Update) != RESET)  //检查TIM4更新中断发生与否
//		{
//		TIM_ClearITPendingBit(TIM4, TIM_IT_Update  );  //清除TIMx更新中断标志 
//		time1--;
//		}
//}


/*
使用
	TIM3_Int_Init(4999,7199);//10Khz的计数频率，计数到5000为500ms  


    TIM_Cmd(TIM7, ENABLE);                            //使能定时器计时
        UsartPrintf(USART1, "\r\nhello word!!n\r\n");
        TIM_Cmd(TIM7, DISABLE);                            //关闭定时器

        time = timer_info.timer7Out * 50000;            //测算时间-中断次数*中断周期
        time += TIM_GetCounter(TIM7);                    //获取当前中断前的剩余值
        TIM_SetCounter(TIM7, 0);                        //清零



*/
